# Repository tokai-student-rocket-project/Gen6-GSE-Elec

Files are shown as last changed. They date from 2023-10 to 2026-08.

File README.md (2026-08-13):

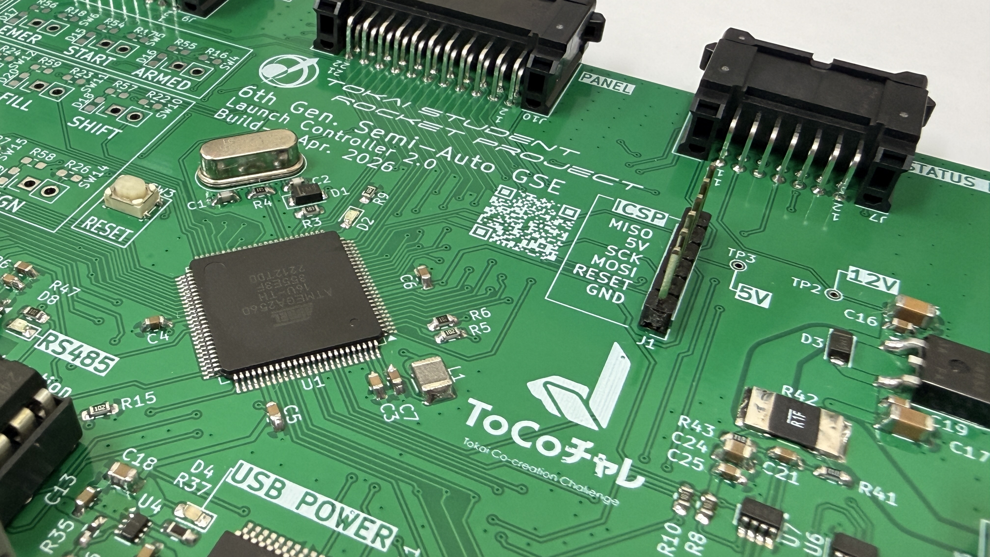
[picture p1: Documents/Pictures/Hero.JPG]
Hero


# 第6世代 Ground Support Equipment (GSE)

**2025年3月8日，H-60号機打上げ実験にて運用をし正常に動作したことを確認しました．**

## システムの特徴
- 🔋 **バッテリー給電 & 小型軽量化**: 従来の大型電源を撤廃し、フィールド運用が容易なバッテリー駆動に対応
- ⚡ **Arduino / PlatformIO 開発**: モジュール化された保守性の高いコード構造と自動ライブラリ管理
- 📊 **高精度 N2O 圧力リアルタイム計測**: VESIM10 圧力センサと ADS1115 ADC による遠隔圧力監視
- 🛡️ **フェールセーフ & 安全インターロック**: セミオートマチックシーケンスおよび緊急停止 (E-STOP) 機能

## 📌 バージョン履歴とシステム構成
本リポジトリでは、開発・運用の進展に合わせて以下のバージョンを管理しています。
| バージョン | 主な特徴・追加機能 | ソースファイル | PlatformIO 環境名 |
|---|---|---|---|
| **Gen6 1.0** | **初代実証版**<br>2025年3月8日 H-60号機打上げ実験にて運用成功。RS485有線通信、セミオートシーケンス | `src/LaunchController/`<br>`src/SatelliteController/` | `[env:Launch]`<br>`[env:Satellite]` |
| **Gen6 2.0** | **安全・安定性強化版**<br>電磁弁故障検出デバウンス、リミットスイッチ安全ゲート監視、ゼロ点校正の安全判定機能を追加、通信アルゴリズムを最適化 | `src/LaunchController2.0/`<br>`src/SatelliteController2.0/` | `[env:Launch2]`<br>`[env:Satellite2]` |

## ギャラリー
- [2025年3月8日 H-60号機打上げ実験](https://github.com/tokai-student-rocket-project/Gen6-GSE-Elec/blob/main/Documents/Pictures/Gallery/Gallery.md)

## ドキュメント
- [仕様](./Documents/Specification.md)
- [パーツリスト](./Documents/)
- [自動シークエンスタイミングの考え方](./Documents/AutoSequence.md)
- [通信・タスク管理ライブラリについて](./Documents/library_guide.md)
- [亜酸化窒素の圧力計測について](./Documents/VESIM10_Manual.md)
  - [校正シート](./Documents/VESIM10_Calibration.xlsx)
  - [試験成績表(TSRP Only)](https://u-tokai.box.com/s/f19nbcfg3vuwrdxsdca0jw9x3lm8z8kp)

## フォルダ構成

## .pio
: 基本的に自動生成されるため必要ないですが，ライブラリの関係で置いてあります．.pioフォルダの役割は外部ライブラリのインストール先とbuild時のファイル生成先です．（たぶん）

## [Document](./Documents/)
: 資料保管場所として使用しています．できる限りの情報を残せるように頑張ります．
## [include](./include/)
: 特に使用していません．(PlatformIO自動生成)
## [KiCad](./KiCad/)
: サテライトコントローラーランチコントローラーの基板が入っています．フォルダ名の通り，オープンソースのEDAである[KiCad](https://www.kicad.org/)を使用して作成しました．バージョンは 8.0 です．(2025年1月中に9.0へと上がるみたいでびっくりしています．)
## [lib](./lib/)
: ライブラリが入っています．新しくライブラリを作成する際はこちらに収納すると分かりやすいです．(PlatformIO自動生成)
## [src](./src/)
: ランチコントローラーとサテライトコントローラーのソースファイルが入っています．Arduinoで記述していますが，[PlatformIO](https://platformio.org/)の仕様上 .ino ファイルではなく，.cppファイルになっています．(PlatformIO自動生成)
## [test](./test/)
: test機能を使っていないので意味はありません．(PlatformIO自動生成)
## [LICENCE](./LICENSE)
: ライセンスを記載しています．
## [platformio.ini](./platformio.ini)
: PlatformIOを使用するための設定ファイルとなっています．参照：[platform.iniについて](#platforminiについて)

## platform.iniについて

platform.iniはPlatformIOを使用するための設定ファイルです．外部ライブラリがインストールされていなくてもこのplatform.iniファイルに記載があれば自動的にインストールしてくるため環境構築を行いやすくなり，とても便利です．参照：[公式](https://docs.platformio.org/en/latest/projectconf/index.html)

platform.iniファイルにはセクションがあり，それぞれに対してKeyとValueのペアがあります．

> [!NOTE]
> ここの説明を読むより，[公式](https://docs.platformio.org/en/latest/projectconf/index.html)の説明を読んだ方が正確で分かりやすいです！

### サテライトコントローラー
[env:Satellite]
> 環境を示しています．今回はサテライトコントローラーの環境になります．

platform = atmelavr
> 使用するマイコンに合わせています．参照：[公式](https://docs.platformio.org/en/latest/projectconf/sections/env/options/platform/platform.html)

board = ATmega2560
> 使用するマイコンが持つ固有の値を入れています．参照：[公式](https://docs.platformio.org/en/latest/projectconf/sections/env/options/platform/board.html)

framework = arduino
> 使用したいフレームワークを指定しています．参照：[公式](https://docs.platformio.org/en/latest/frameworks/index.html#frameworks)

monitor_speed = 115200
> シリアルモニターのボーレートを指定しています．なお，VScodeの拡張機能である Serial Monitor を使用する場合は拡張機能側で設定する必要があるため関係ありません．

upload_protocol = arduinoisp
> ArduinoISP を使用して書き込むため指定しています．（シリアル変換ICの影響か，USB経由で書き込みができなかったため．つけていて良かった．）

upload_speed = 19200
> ArduinoISP 周りの設定です．
upload_flags = ...
> ArduinoISP 周りの設定です．
upload_command = ...
> ArduinoISP 周りの設定です．

build_src_filter = +<SatelliteController/SatelliteController.cpp>
> env:Satellite の環境に書き込みたいソースファイルを指定できます．

lib_deps = ...
> 外部ライブラリを指定しています．

### ランチコントローラー
[env:Launch]
platform = atmelavr
> 環境を示しています．今回はランチコントローラーの環境になります．

board = ATmega2560
> [platform.ini > サテライトコントローラー参照](#サテライトコントローラー)

framework = arduino
> [platform.ini > サテライトコントローラー参照](#サテライトコントローラー)

monitor_speed = 115200
> [platform.ini > サテライトコントローラー参照](#サテライトコントローラー)

lib_deps = ...
> [platform.ini > サテライトコントローラー参照](#サテライトコントローラー)

build_src_filter = +<LaunchController/LaunchController.cpp>
> [platform.ini > サテライトコントローラー参照](#サテライトコントローラー)

### 手順書
- [せいさくちゅう](./)

### データフロー

- [ランチコントローラー](./Documents/Pictures/DataFlowDiagram/LaunchController_DataFlowDiagram.png)

- [サテライトコントローラー](./Documents/Pictures/DataFlowDiagram/SatelliteController_DataFlowDiagram.png)

## License

Copyright (c) 2025 Tokai Student Rocket Project

This project is licensed under the MIT License. See the [LICENSE](https://github.com/tokai-student-rocket-project/Gen6-GSE-Elec/blob/main/LICENSE) file for mare details.

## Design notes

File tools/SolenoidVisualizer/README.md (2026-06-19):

# Gen6-GSE Solenoid Visualizer

Gen6-GSEシステムの電磁弁（ソレノイド）の動作状態を可視化・シミュレーションするためのGUIツールです．

## 動作要件 (Requirements)

Python 3 環境が必要です．
実行前に以下の外部ライブラリを `pip` でインストールしてください．

```bash
pip install customtkinter pyserial
```

※ `tkinter` は通常Pythonに標準で同梱されていますが，Linux環境等では別途インストールが必要な場合があります（例: `sudo apt-get install python3-tk`）．

## 実行方法 (How to Run)

Pythonインタプリタを使用して `main.py` を実行します．
（注: `python tools/SolenoidVisualizer` のようにディレクトリを指定するだけではエラーになります．必ず `main.py` まで指定してください）

**方法1: プロジェクトのルートディレクトリから実行する場合**
```bash
python tools/SolenoidVisualizer/main.py
```

**方法2: ツールのディレクトリに移動して実行する場合**
```bash
cd tools/SolenoidVisualizer
python main.py
```

## 主な機能 (Features)

- **シリアル通信モニタ:** Launch Controllerとシリアル通信で接続し，リアルタイムのコマンド(CMD)とフィードバック(FB)の状態を可視化します．
- **デバッグモード (DEBUG MODE):** ハードウェアがなくても，チェックボックスから各電磁弁を強制的にON/OFFし，配管内の流体（GN2, LN2O, GO2）の動きをシミュレーションできます．
- **自動シーケンス (AUTO LAUNCH):** `LaunchController2.0.cpp` のタイミング（充填，酸素，点火，主弁開，パージなど）に合わせた自動打ち上げシーケンスをGUI上でテスト・可視化できます．

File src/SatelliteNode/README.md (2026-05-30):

# SatelliteNode

Seeed XIAO SAMD21 を用いたサテライトノードのファームウェアです。  
リミットスイッチの状態を RS485 通信で SatelliteController2.0 に送信します。

---

## ハードウェア構成

### マイコン

| 項目 | 内容 |
|---|---|
| ボード | Seeed XIAO SAMD21 |
| フレームワーク | Arduino (PlatformIO) |
| 環境名 | `SatelliteNode` |

### ピン配置

| 機能 | ハード記述 | Arduino ピン | 説明 |
|---|---|---|---|
| RS485 RE/DE 制御 | GPIO0 | D0 | HIGH=送信, LOW=受信 |
| 5V電源電圧計測 (ADC) | GPIO1 | A1 | 10kΩ×2 分圧入力 |
| RS485 DI (TX) | GPIO16 | D6 | `Serial1` TX |
| RS485 RO (RX) | GPIO17 | D7 | `Serial1` RX |
| I2C SDA | GPIO22 | D4 | `Wire` SDA |
| I2C SCL | GPIO23 | D5 | `Wire` SCL |

### RS485 トランシーバ (ADM2582E)

| ADM2582E ピン | 接続先 |
|---|---|
| RE (Low=受信有効) | D0 (GPIO0) |
| DE (High=送信有効) | D0 (GPIO0) |
| DI | D6 / TX (GPIO16) |
| RO | D7 / RX (GPIO17) |

RE と DE は同一ピンに接続されており，HIGH で送信モード，LOW で受信モードとなります。

### IOエキスパンダー (MCP23017)

I2C アドレス: `0x20` (A0〜A2 = GND)

| MCP23017 ピン | 論理チャンネル | 方向 | 説明 |
|---|---|---|---|
| GPA0 | チャンネル2 | 入力 | リミットスイッチ入力2 (74HC14経由) |
| GPA1 | チャンネル1 | 入力 | リミットスイッチ入力1 (74HC14経由) |
| GPA2 | チャンネル0 | 入力 | リミットスイッチ入力0 (74HC14経由) |
| GPA3 | チャンネル5 | 入力 | リミットスイッチ入力5 (74HC14経由) |
| GPA4 | チャンネル4 | 入力 | リミットスイッチ入力4 (74HC14経由) |
| GPA5 | チャンネル3 | 入力 | リミットスイッチ入力3 (74HC14経由) |
| GPB0 | — | 出力 | LED制御0 (チャンネル0対応) |
| GPB1 | — | 出力 | LED制御1 (チャンネル1対応) |
| GPB2 | — | 出力 | LED制御2 (チャンネル2対応) |
| GPB3 | — | 出力 | LED制御3 (チャンネル3対応) |
| GPB4 | — | 出力 | LED制御4 (チャンネル4対応) |
| GPB5 | — | 出力 | LED制御5 (チャンネル5対応) |

> **注意**: 74HC14 はシュミットトリガインバータです。  
> リミットスイッチが押される（導通する）と 74HC14 の入力が LOW となり，出力が HIGH になります。  
> そのため，`MCP23017 GPA ピン = HIGH` のとき，対応するリミットスイッチが押されていることを意味します。

### A/D 変換（5V電源電圧計測）

```
5V 電源
  │
  ├─ 10kΩ (R1, 1%)
  │
  ├─── A1 (ADC 入力)
  │
  ├─ 10kΩ (R2, 1%)
  │
GND
```

分圧比 = R2 / (R1 + R2) = 10k / 20k = **0.5**

ADC 基準電圧は 3.3V，分解能は 10bit です。

計算式:
```
V_adc = (analogRead(A1) / 1023.0) × 3.3
V_supply = V_adc / 0.5 = V_adc × 2.0
```

---

## ソフトウェア仕様

### 送信パケット

| パケット種別 | 値 | 内容 |
|---|---|---|
| `LIMIT_SWITCH_SYNC` | 10 | リミットスイッチ状態 (uint8_t) |
| `COM_CHECK_S_TO_L` | 4 | 生存確認 |

#### LIMIT_SWITCH_SYNC ビット定義

| ビット | チャンネル | 押されているとき |
|---|---|---|
| Bit0 | チャンネル0 (GPA2) | `1` |
| Bit1 | チャンネル1 (GPA1) | `1` |
| Bit2 | チャンネル2 (GPA0) | `1` |
| Bit3 | チャンネル3 (GPA5) | `1` |
| Bit4 | チャンネル4 (GPA4) | `1` |
| Bit5 | チャンネル5 (GPA3) | `1` |

### 受信パケット

| パケット種別 | 値 | 内容 |
|---|---|---|
| `COM_CHECK_L_TO_S` | 3 | 生存確認 (受信時刻を更新) |

### タスク周期

| タスク | 周期 |
|---|---|
| リミットスイッチ状態送信 | 10 Hz |
| 5V電源電圧計測 | 5 Hz |
| 生存確認送信 | 2 Hz |

---

## ビルド方法

```bash
# PlatformIO CLI の場合
pio run -e SatelliteNode

# 書き込み
pio run -e SatelliteNode -t upload
```

> `platformio.ini` の `[env:SatelliteNode]` に以下を追加する必要があります（詳細は `SatelliteNode_bugs.md` を参照）。

---

## 依存ライブラリ

| ライブラリ | 用途 |
|---|---|
| `Lib_MCP23017` (本プロジェクト内) | MCP23017 IOエキスパンダー制御 |
| `hideakitai/MsgPacketizer` | RS485 パケット通信 |
| `hideakitai/TaskManager` | 定周期タスク管理 |

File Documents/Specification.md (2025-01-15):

# 第6世代 Ground Support Equipment (GSE) 仕様

## ランチコントローラー
<div align = "center">
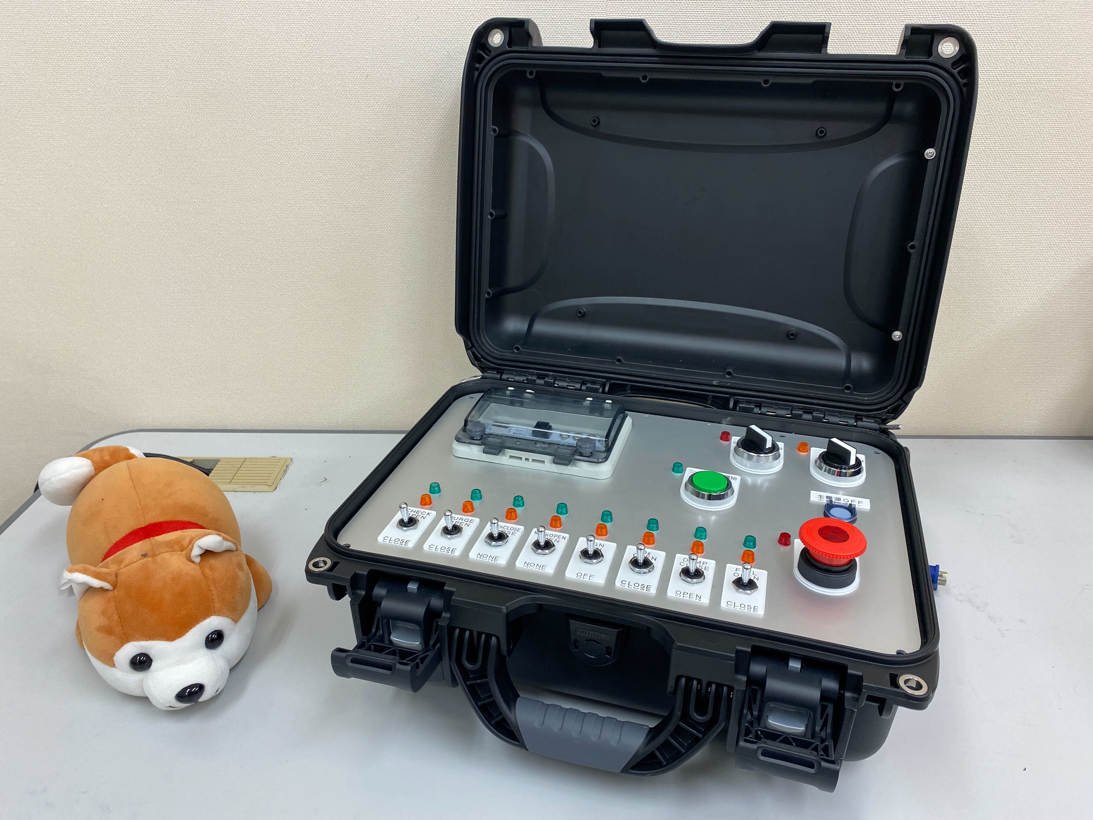
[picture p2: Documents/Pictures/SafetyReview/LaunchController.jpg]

</div>

ロケットから離れた点火所から酸化剤充填を行うコントローラーです．
セミオートマチックシークエンスに対応しています．

### 電源

電源はポータブルバッテリーから得る想定で設計されていますが，12 V（DC）の AC アダプターを使用できればどのような電源でも構いません．
DCジャックは**センタープラス**なので，センタープラスのACアダプターを使用してください．

### 通信

サテライトコントローラーとRS485を用いて有線通信しています．

|通信仕様||
|-|-|
|想定通信距離|100 m 以上|
|ケーブル|LANケーブル（ツイストペア・シールド無し）|
|コネクタ|RJ45モジュラージャック|

### インターフェース

ランチコントローラーには各種装置と接続するためのインターフェースがついています．

#### 左側面

|名称|個数|説明|
|-|-|-|
|2.1 mm DCジャック|3|充填確認スイッチが接続できます．|
|3.5 mm ステレオミニジャック|1|外部音声出力ポートです．AUXケーブルを使用できます．|

#### 右側面
|名称|個数|説明|
|-|-|-|
|2.1 mm DCジャック|1|電源入力に使います．参照：[電源](#電源)|

#### 背面
|名称|個数|説明|
|-|-|-|
|RJ45モジュラージャック|1|通信ケーブルを接続し，サテライトコントローラーと有線通信を行います．|

## パネル
<div align = "center">
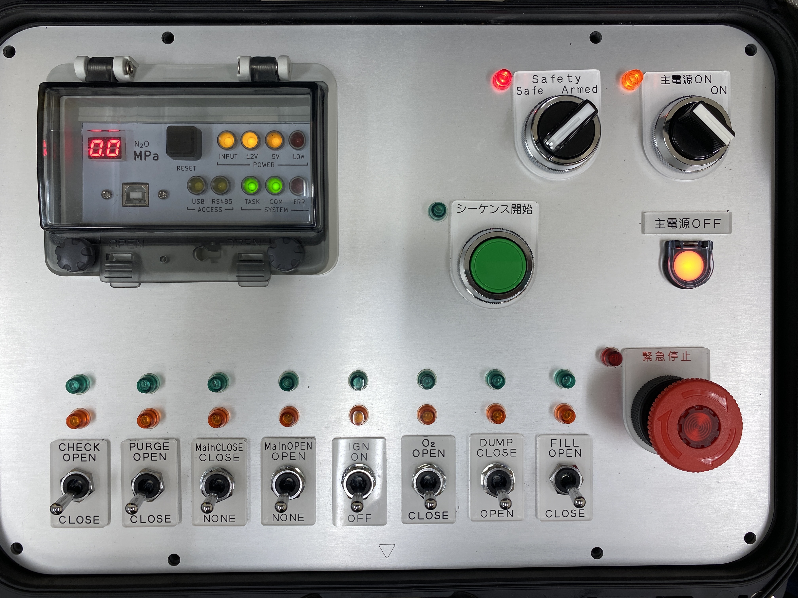
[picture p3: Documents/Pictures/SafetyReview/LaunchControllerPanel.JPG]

</div>

ロケットを打上げる操作パネルとなっています．

画像左上はステータスパネルとなっており，GSEの状態確認ができるようになっています．プログラムを書き込み時やデバッグ時にハッチを開けて USB Type-B を介してマイコンにアクセスできるようになっている．

> [!NOTE]
> シリアルポートはSerialを使用できます．
> 
> Serial.begin(115200)で初期化．
> Serial.println()で任意の値を取得することができます．

## サテライトコントローラー
<div align = "center">
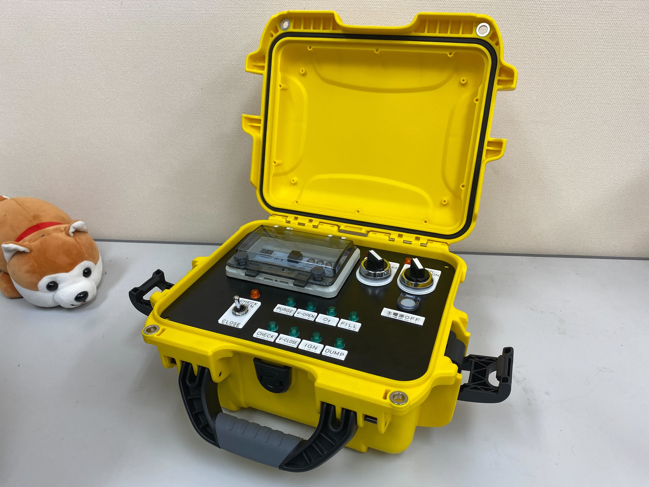
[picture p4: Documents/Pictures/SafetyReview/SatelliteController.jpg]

</div>

ロケットの近くに設置され，ランチコントローラーからの指令を受けて，各種装置へ出力を行う中継装置です．

最大6個の電磁弁に対応しています．

#### 電源
ランチコントローラーと同様に電源はポータブルバッテリーから得る想定で設計していますが，12 V(AC)アダプターを使用できればどのような電源でも構いません．
DCジャックは**センタープラス**なので，センタープラスのACアダプターを使用してください．

#### 通信
ランチコントローラーとRS485を用いて通信しています．

|通信仕様||
|-|-|
|想定通信距離|100 m 以上|
|ケーブル|LANケーブル（ツイストペア・シールド無し）|
|コネクタ|RJ45モジュラージャック|

#### インターフェース

サテライトコントローラーは中継装置の役割をしているため各種装置へつながる便利なインターフェースがついています．

#### 左側面

|名称|個数|説明|
|-|-|-|
|コネクタ（4ピン・大）|1|アンビリカルケーブルを接続します．IGN，バルブOPENの信号を出力します．|

#### 右側面
|名称|個数|説明|
|-|-|-|
|2.1 mm DCジャック|1|電源入力に使います．参照：[電源](#電源)|

#### 背面
|名称|個数|説明|
|-|-|-|
|RJ45モジュラージャック|1|通信ケーブルを接続し，サテライトコントローラーと有線通信を行います．|
|コネクタ（2ピン）|1|こもあユニットへ接続します．12 Vを出力します．|
|コネクタ（4ピン・小）|1|将来的に亜酸化窒素の圧力を読み取る圧力センサが取り付けられます．|
|コネクタ（11ピン）|1|電磁弁ユニットへ接続します．|

## こもあユニット
<div align = "center">
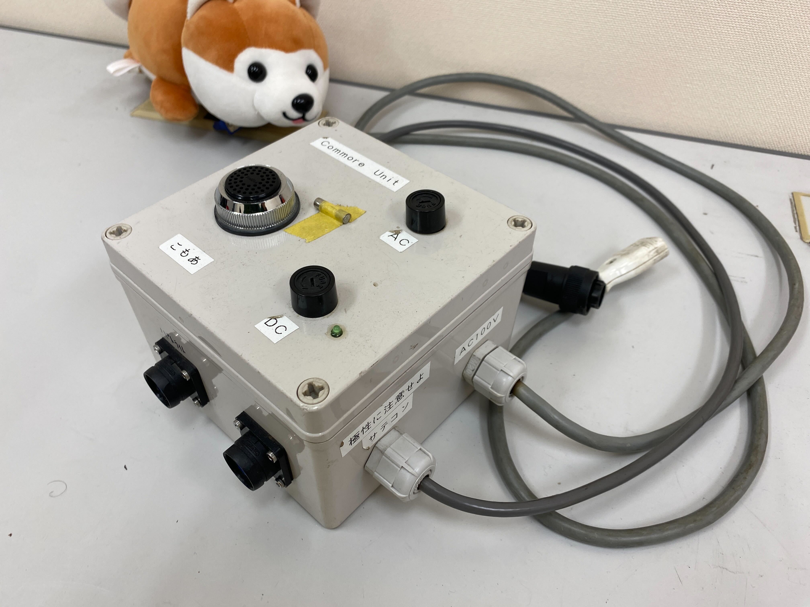
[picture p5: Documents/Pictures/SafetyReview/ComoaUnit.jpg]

</div>

1次側に信号が入力されると2次側にAC100V出力します．リレーと同じ役割をしています．

## アンビリカルケーブル
<div align = "center">
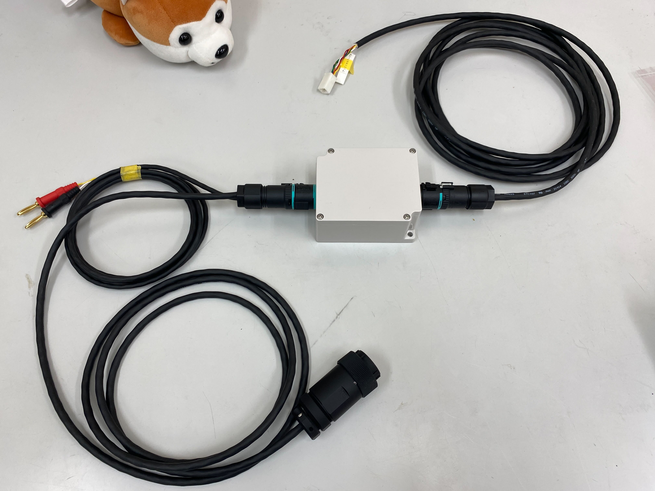
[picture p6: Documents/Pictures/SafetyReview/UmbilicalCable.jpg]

</div>

ロケットに電力と信号を供給するためのケーブルです．画像中央のBOXを基準とし，右側がロケットに接続（搭載計器）され，左側が電源とサテライトコントローラーに接続されます．左側にある黒色のコネクタが4ピンコネクタ・大です．

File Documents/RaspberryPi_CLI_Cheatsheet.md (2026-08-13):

# Raspberry Pi 4 CLI 活用・運用チートシート (Gen6 GSE System)

本ドキュメントは，Gen6 GSE システム（Launch3.0 / Satellite3.0）の無線遠隔制御ノードとして使用する **Raspberry Pi 4 の環境構築，ネットワーク設定，遠隔制御プログラムの起動・デバッグ，systemd サービス管理，電源操作** において頻繁に使用する CLI コマンドをまとめた活用ガイドです．

---

## 1. 接続・ネットワーク疎通確認 (SSH & IP)

| コマンド | 説明 |
|---|---|
| `ssh pi@raspi-gse.local` | mDNS ホスト名指定で SSH ログイン |
| `ssh pi@192.158.x.x` | IP アドレス直接指定で SSH ログイン |
| `hostname -I` *(または `ip a`)* | Raspberry Pi に割り当てられている IP アドレスを確認 |
| `ping 192.158.x.x` | PC から Raspberry Pi へのネットワーク疎通確認 |

---

## 2. 固定 IP アドレス設定 (NetworkManager)

Raspberry Pi OS (Debian Bookworm) では NetworkManager を使用して固定 IP（`192.158.x.x` 等）を設定します．

| コマンド | 説明 |
|---|---|
| `sudo nmtui` | GUI 風の対話画面で Wi-Fi および固定 IP アドレスを設定（推奨） |
| `nmcli connection show` | 現在認識されているネットワーク接続名の一覧を表示 |
| `sudo nmcli connection modify "<接続名>" ipv4.method manual ipv4.addresses 192.158.x.x/24 ipv4.gateway 192.158.x.1` | コマンドラインで指定の IP アドレスを固定化 |
| `sudo nmcli connection up "<接続名>"` | 変更したネットワーク設定を即時適用 |

---

## 3. OS 更新・パッケージ管理 (Apt & Pip)

| コマンド | 説明 |
|---|---|
| `sudo apt update && sudo apt upgrade -y` | OS パッケージリスト更新と全パッケージの最新化 |
| `sudo apt install -y python3-pip python3-serial python3-msgpack python3-flask git` | 遠隔制御システムに必要な依存パッケージを一括インストール |
| `pip3 install -r requirements.txt --break-system-packages` | `raspi_gse_control` の Python パッケージ依存関係を適用 |

---

## 4. 制御プログラムの配置と実行 (GSE Control Server)

| コマンド | 説明 |
|---|---|
| `scp -r d:\Projects\TSRP\Gen6-GSE-Elec\tools\raspi_gse_control pi@192.158.x.x:~/` | Windows PC から Raspberry Pi へ制御プログラム一式を SCP 転送 |
| `python3 raspi_gse_control.py --demo` | **デモ / シミュレータモード** 起動（マイコン実機なしで通信・Web UI テスト可能） |
| `python3 raspi_gse_control.py --port /dev/ttyUSB0` | **実機接続モード** 起動（ATmega2560 マイコンと USB シリアル接続） |

---

## 5. ターミナル CLI デバッグコマンド (`GSE-Debug>` プロンプト内)

`raspi_gse_control.py` 起動後に画面に表示される `GSE-Debug>` 画面での直感操作コマンドです．

| コマンド | 引数例 | 説明 |
|---|---|---|
| `status` | - | 現在の圧力（MPa），セーフティ，リミットスイッチ，各弁状態（CMD/FB）一覧表示 |
| `arm` | `on` / `off` | 遠隔セーフティ装置の解除 (ARM) / 施錠 (DISARM) |
| `fill` | - | 遠隔充填シーケンス開始 |
| `ignite` | - | 遠隔点火シーケンス開始 |
| `estop` | - | 🚨 **緊急停止 (EMERGENCY STOP)**（DUMP, PURGE 開，全安全退避） |
| `peace` | - | 通常停止 (PEACEFUL STOP) |
| `valve` | `FILL 1` | 指定電磁弁の手動トグル (`SHIFT`, `FILL`, `DUMP`, `OXYGEN`, `IGNITER`, `OPEN`, `CLOSE`, `PURGE`) |
| `limit` | `1` / `0` | リミットスイッチ (ch5) の模擬押下 / 解放 |
| `zero` | - | 圧力センサーの遠隔ゼロ点校正要求 |
| `quit` | - | GSE デバッグターミナルおよびサーバーの終了 |

---

## 6. 自動起動サービス管理 (systemd)

実験場等で電源投入時にバックグラウンドで自動起動・継続稼働させるための管理コマンドです．

| コマンド | 説明 |
|---|---|
| `sudo cp raspi-gse.service /etc/systemd/system/` | サービス設定ファイルを配置 |
| `sudo systemctl daemon-reload` | systemd にサービス定義を再読み込み |
| `sudo systemctl enable raspi-gse.service` | OS 起動時の自動スタートを有効化 |
| `sudo systemctl start raspi-gse.service` | 今すぐバックグラウンドサービスを起動 |
| `sudo systemctl stop raspi-gse.service` | バックグラウンドサービスを一時停止 |
| `sudo systemctl status raspi-gse.service` | サービスの現在状態（稼働中/停止中）を表示 |
| `journalctl -u raspi-gse.service -f` | 自動起動プログラムのリアルタイム標準出力ログを監視 |

---

## 7. 電源操作 (Shutdown & Reboot)

> [!CAUTION]
> SD カードのデータ破損を防ぐため，電源プラグを抜く前に必ず安全なシャットダウンコマンドを実行してください．

| コマンド | 説明 |
|---|---|
| `sudo shutdown -h now` *(または `sudo poweroff`)* | **安全なシャットダウン**（緑色のアクセス LED 消灯を確認後に電源抜去） |
| `sudo reboot` | システムの即時再起動 |

---

## 8. 関連ドキュメントリンク

* [RaspberryPi_OS_Comparison_and_Setup.md](file:///d:/Projects/TSRP/Gen6-GSE-Elec/Documents/RaspberryPi_OS_Comparison_and_Setup.md)
* [RaspberryPi_Debug_and_Demo_Guide.md](file:///d:/Projects/TSRP/Gen6-GSE-Elec/Documents/RaspberryPi_Debug_and_Demo_Guide.md)
* [Launch3_Satellite3_Wireless_Guide.md](file:///d:/Projects/TSRP/Gen6-GSE-Elec/Documents/Launch3_Satellite3_Wireless_Guide.md)
* [raspi-gse.service](file:///d:/Projects/TSRP/Gen6-GSE-Elec/tools/raspi_gse_control/raspi-gse.service)

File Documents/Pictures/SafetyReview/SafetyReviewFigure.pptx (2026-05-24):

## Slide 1

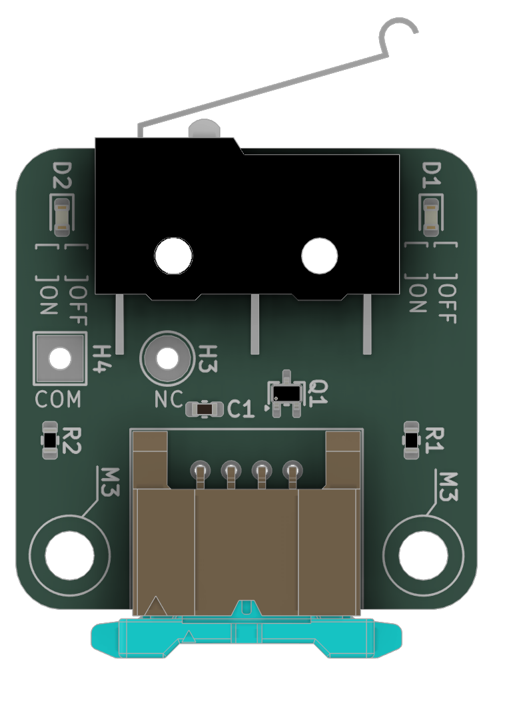
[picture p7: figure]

検知

スイッチ

※配線し
はんだ付け

信号出力

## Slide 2

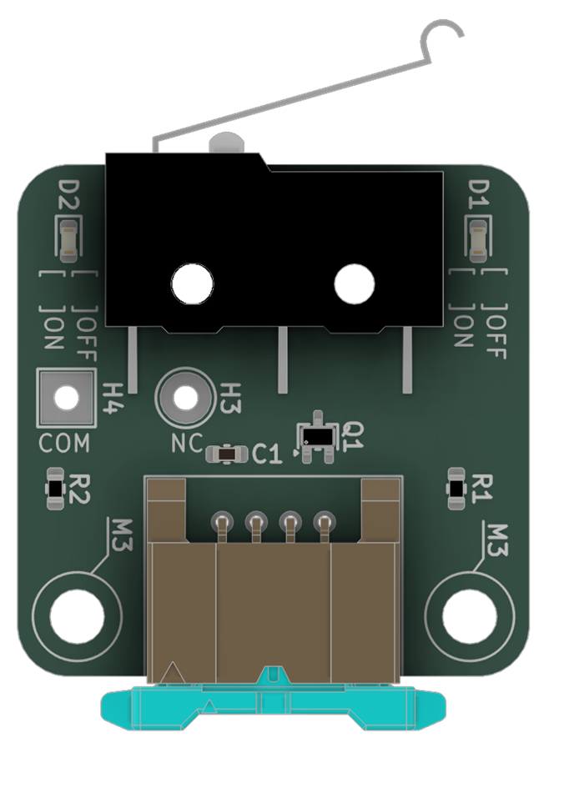
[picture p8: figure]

検知

1 2 3 4

| 1 | 2 | 3 | 4
ピン名 | GND | 3.3V IN | SW OUT | LED CTRL
機能 | 基準電位 | 電源入力 | 出力 | LED制御

信号出力

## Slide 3

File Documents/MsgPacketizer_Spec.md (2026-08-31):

# MsgPacketizer システム仕様とトラブルシューティング記録

## 概要
Arduino/MCU 側で `MsgPacketizer` ライブラリを使用してシリアル通信を行う際、C++（PlatformIO）側の必須ビルドオプションと、Raspberry Pi（Python）側で正しくデータを受信・送信するための仕様、およびデバッグで判明したトラブルの根本原因を記録する。

## C++ (PlatformIO) 側の必須ビルドオプション (`platformio.ini`)

MsgPacketizer および内部で使用される MsgPack は、マイコンの貴重なメモリ（RAM）を節約するため、静的なメモリ確保を行っています。そのため、デフォルトではかなり厳しい要素数・登録数の上限が設定されています。
今回の GSE/サテライトシステムでは扱うデータ量や通信ポートが多いため、`platformio.ini` の `build_flags` にて以下のマクロを定義して上限を拡張しています。

### 1. `-D PACKETIZER_MAX_STREAM_MAP_SIZE=4`
- **概要:** MsgPacketizer が同時に処理（監視）できる通信ストリーム（`Serial` や `Serial1`、`Wire` など）の最大登録数を指定する設定。
- **解説:** 今回のシステムでは、LaunchController が「デバッグ・RasPi通信用のUSB (`Serial`)」と「サテライト通信用のRS485 (`Serial1`)」の **2つのシリアルストリーム** を同時に監視・パースする必要があります。デフォルトの上限設定（通常は1か2）では複数ポートの同時登録が弾かれてしまうリスクがあるため、安全率を見込んで最大 `4` ストリームまで処理できるように拡張しています。
- **影響:** この設定が不足していると、後から登録したシリアルポートからのパケットが無視され、`MsgPacketizer::update()` を呼んでもコールバックが一切呼ばれなくなるという原因不明の通信不良に陥ります。

### 2. `-D PACKETIZER_MAX_CALLBACK_QUEUE_SIZE=12`
- **概要:** 登録できるコールバック関数（`subscribe`）の最大数を指定する設定。
- **解説:** コマンドの種類（バルブ制御、テレメトリ、Ping等）が増えて `subscribe` を多数登録しようとした際、デフォルト上限を超えると後から登録したコマンドが反応しなくなります。これを 12 に増やすことで、多数のコマンドを漏れなく受け付けられるようにしています。

### 3. `-D MSGPACK_MAX_ARRAY_SIZE=12`
- **概要:** MsgPack の1つの配列（リスト）に格納できる要素数の上限設定。
- **解説:** デフォルト上限は 8個です。テレメトリデータ（圧力、電圧、各バルブ状態など）の変数が 9個以上に増えた際、デフォルトのままでは送信時のエンコード処理が失敗してデータが一切送られなくなります。これを回避するために 12 に拡張しています。

---

## MsgPacketizer のプロトコル仕様 (C++ -> Python)
MsgPacketizer が生成するシリアル通信の1フレームは以下の構造になっている。

```text
[COBS Overhead/Lengths] [Packet ID (Index)] [MsgPack Data Payload] [CRC8] [0x00 (Delimiter)]
```

### 1. COBS (Consistent Overhead Byte Stuffing)
- **仕様:** 
  - フレームの区切り文字として `0x00` を使用する。
  - データペイロード内に `0x00` が含まれる場合、そのまま送信するとフレームの区切りと誤認されるため、COBSエンコードによって `0x00` が排除され、次の `0x00` までの長さを示すバイトに置き換えられる。
- **注意点:** 
  - 受信側（Python）は、MsgPackのデコードを行う**前**に、必ずCOBSデコードを行い、元のペイロードを復元しなければならない。これを怠ると、データ中に `0x00`（例：値が `0` の整数など）が含まれた瞬間にパケットが破損したように見え、以降のデコードが失敗する。

### 2. CRC8 チェックサムの計算範囲
- **仕様:**
  - 多項式: `0x07` (SMBus / FastCRC8::smbus と同等)
  - 計算範囲: **MsgPack データペイロード本体のみ（`packet_id` を除く）**
- **注意点:**
  - Python 側で CRC を計算・検証する際、`[packet_id] + [msgpack data]` の全体に対して CRC を計算すると不一致となる。必ず `packet_id` を除外した `[msgpack data]` 部分に対して CRC8 を計算すること。

### 3. `send()` と `send_arr()` の違いと Python 側の受け皿
- **仕様:**
  - `MsgPacketizer::send()`: 引数を MsgPack の「独立した複数の要素」として直列にエンコードする。
  - `MsgPacketizer::send_arr()`: 引数を MsgPack の「1つの配列（Array）」としてエンコードする。
- **注意点:**
  - 今回実装した Python のシリアルワーカーでは、どちらの関数で送信されても問題なく処理できるように、受信した全要素を Python 側で強制的に1つのリスト `[packet_id, arg1, arg2...]` にパッキング（またはアンラップ）して後続の処理に渡すラッパー機構を実装した。

---

## 今回発生したトラブルと原因リスト

1. **配列の要素数制限による送信失敗**
   - **症状:** 新たに入力電圧と12Vバス電圧の2つの要素を追加したところ、データが全く送信されなくなった。
   - **原因:** 追加により引数が 9 個となり、デフォルトの `MSGPACK_MAX_ARRAY_SIZE` (8) を超過してエンコードが失敗していた。
   - **解決策:** `platformio.ini` に `-D MSGPACK_MAX_ARRAY_SIZE=12` を追記。

2. **COBS エンコード未対応によるパケット崩壊**
   - **症状:** Python スクリプトでは全くデータを受信できなかった。
   - **原因:** 元の Python スクリプトに COBS デコードが実装されておらず、シリアルの生データを直接 MsgPack デコーダに流し込んでいた。リミットスイッチのダミー値として `0`（`0x00`）を入れた瞬間に COBS によるバイト置換が発動し、MsgPack としての構造が崩壊した。
   - **解決策:** Python スクリプト内に `cobs_decode` および `cobs_encode` を自前で実装し、パケットを抽出してから MsgPack デコーダに渡すように修正。

3. **CRC8 計算範囲の仕様不一致による全破棄**
   - **症状:** COBS デコードを実装しても、依然としてデータが更新されず、Python からの送信コマンドも MCU に無視された。
   - **原因:** Python 側で「パケットID」を含めて CRC8 を計算していたが、C++ 側の Packetizer は「パケットIDを含めず、データ本体のみ」で CRC を計算・照合する仕様だったため。
   - **解決策:** Python の CRC8 計算処理を修正し、`packet_id` を除外した `msgpack` バイト列のみを対象にチェックするように変更した。

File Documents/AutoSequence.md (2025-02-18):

# 自動シークエンスタイミングの考え方

## 基本的な考え方
酸化剤充填が完了した時，つまり充填確認スイッチが押された時を基準としてシークエンスが進む．
シークエンスが進む順番は以下の通り．
> FILL: 酸化剤充填 / パージ: 窒素放出による消火

1. FILL 開始
2. 酸素充填開始
3. イグナイター点火開始
4. バルブ開
5. FILL 停止
6. 酸素充填停止
7. イグナイター点火停止
8. パージ開始
9. パージ停止

## ignition関数

基本的なシークエンスをプログラムでは void sequence::ignition() が担っている．戻り値なし，引数なしの sequence 名前空間，ignition関数である．

ignition関数を下記に示す．

```
void sequence::ignition()
{
    // 重複実行防止
    if (sequence::ignitionSequenceIsActive)
        return;
    
    // 通信失敗したら点火シーケンスに進めない
    if (!communication::statusLamp.isHigh())
    {
        sequence::peacefulStop();
        return;
    }

    // エマスト中は点火シーケンスを始めない
    if (sequence::emergencyStopSequenceIsActive)
        return;

    // 充填開始前は点火シーケンスを始めない
    if (!control::fill.isAutomaticRaised())
        return;

    // 手動のFILLがONの間は点火シーケンスを始めない
    if (control::fill.isManualRaised())
        return;

    sequence::ignitionSequenceIsActive = true;
    sequence::canConfirm = false;

    control::sequenceStart.setAutomaticOn();
    mp3_play(4); // 0104_ignitionSequenceStart

    Tasks[control::OXYGEN_START]->startOnceAfterSec(4.5);

    Tasks[control::IGNITER_START]->startOnceAfterSec(6.0);

    Tasks[control::FILL_STOP]->startOnceAfterSec(10.0);
    Tasks[control::OPEN_START]->startOnceAfterSec(10.0);

    Tasks[control::OXYGEN_STOP]->startOnceAfterSec(10.5);
    Tasks[control::IGNITER_STOP]->startOnceAfterSec(10.5);
    Tasks[control::PURGE_START]->startOnceAfterSec(20.5);
    Tasks[control::PURGE_STOP]->startOnceAfterSec(25.5);
}
```
ここから特に必要な箇所を下記に示す．

```
    mp3_play(4); // 0104_ignitionSequenceStart

    Tasks[control::OXYGEN_START]->startOnceAfterSec(4.5);

    Tasks[control::IGNITER_START]->startOnceAfterSec(6.0);

    Tasks[control::FILL_STOP]->startOnceAfterSec(10.0);
    Tasks[control::OPEN_START]->startOnceAfterSec(10.0);

    Tasks[control::OXYGEN_STOP]->startOnceAfterSec(10.5);
    Tasks[control::IGNITER_STOP]->startOnceAfterSec(10.5);
    Tasks[control::PURGE_START]->startOnceAfterSec(20.5);
    Tasks[control::PURGE_STOP]->startOnceAfterSec(25.5);
```
上の行から順番に見ていく．
```
    mp3_play(4); // 0104_ignitionSequenceStart
```
この行はマイクロSDカードに保存された4番目のファイルを指定し音声出力している．つまり，「充填が確認されました．点火します．5秒前 4, 3, 2, 1」である．
```
    Tasks[control::OXYGEN_START]->startOnceAfterSec(4.5);
```
この行からシークエンスの動作を実行している．イメージは「Tasks」というやることリストに「control::OXYGEN_START」を追加し，startOnceAfterSec(4.5)にあるように，4.5秒後に1度だけ実行するといった感じ．
「control::OXYGEN_START」は酸素の流路につながっている電磁弁をONにするという動作．

ここで，Tasks[control::OXYGEN_START]->startOnceAfterSec(4.5); をよく観察してみると主に2つの要素で出来上がっていることが分かる．
1つ目は control::OXYGEN_START，2つ目は startOnceAfterSec(4.5) である．
1つ目の control::OXYGEN_START は電磁弁の動作に置き換えると分かりやすいと思う．さらに，startOnceAfterSec(4.5) も（）の中の数字を n とおけば，n 秒後に動作する指示であることがなんとなく分かると思う．

続いて，この行を見ていく．
```
    Tasks[control::IGNITER_START]->startOnceAfterSec(6.0);
```
こちらも，やることリストに追加していくイメージは変わらない．
「Tasks」というやることリストに「control::IGNITER_START」を追加し，startOnceAfterSec(6.0) のとおり，6.0秒後に1度だけ実行する．

ここで，[基本的な考え方](#基本的な考え方)に戻ってみると，今まで見てきたことは2. 3. の項目に書かれていた動作と一致すると思う．これは，プログラムのルールとして，上から下に実行されるためである．そのため，これ以降の動作も[基本的な考え方](#基本的な考え方)に書かれている通りの順番で実行されていく．

## 実行タイミングの考え方
ここまで，シークエンスとプログラムの対応関係について見てきたがここからはその動作がどのタイミングで実行されるのかを見ていく．

基本的には，startOnceAfterSec()の引数を見ていけば良い．（）の中に書いてある有効数字2桁の数が引数である．

下記の行から見ていく．
```
    Tasks[control::OXYGEN_START]->startOnceAfterSec(4.5);
```
この行では startOnceAfterSec()の引数が4.5である．この理由は，この以前の動作
```
    mp3_play(4); // 0104_ignitionSequenceStart
```
にて「充填が確認されました．点火します．5秒前」を言い終わるまでに4.5秒必要なためである．
これは，ignition関数が呼ばれた直後から4.5秒後に実行されると考えるとさらに分かりやすいと思う．

では，エンジンに点火するタイミングつまり，主流路弁が開するタイミングは
```
    Tasks[control::OPEN_START]->startOnceAfterSec(10.0);
```
となっており，ignition関数が呼ばれた直後から10.0秒後である．この時間を基準として点火操作を時系列順にまとめればどの動作がどのタイミングで実行されるか理解しやすいと思う．

時系列順に整理した点火シークエンスを下記に示す．

|T|実行時間|動作|引数の値|
|-|-|-|-|
|T+|15|パージ 停止|25.5|
|T+|10|パージ 開始|20.5|
|T+|0.5|酸素充填 停止|10.5|
|T+|0.5|イグニッション 停止|10.5|
|T-|0|FILL 停止|10.0|
|T-|0|主流路弁 開|10.0|
|T-|4|イグニッション 開始|6.0|
|T-|5|酸素充填 開始|4.5|

音声と合うように0.1秒単位でそろえるのは難しい．ちょっとずれる．

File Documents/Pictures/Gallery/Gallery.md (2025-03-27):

# 第6世代GSE

## H60 大樹町 2025/03/08

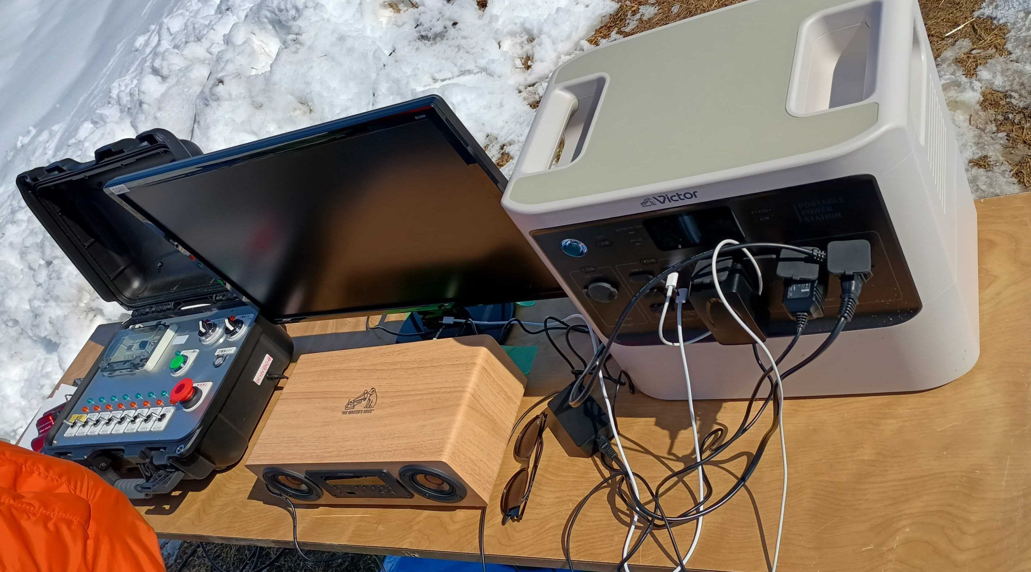
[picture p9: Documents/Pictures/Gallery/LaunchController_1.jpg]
LaunchController_Taiki


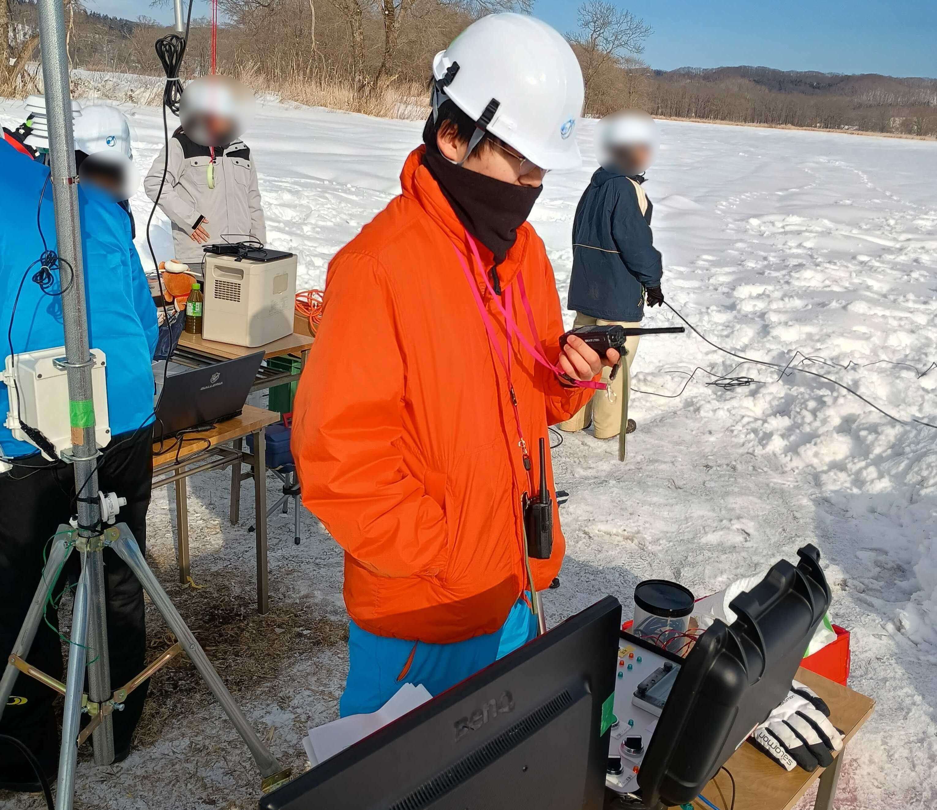
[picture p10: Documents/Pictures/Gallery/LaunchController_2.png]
LaunchController_Taiki


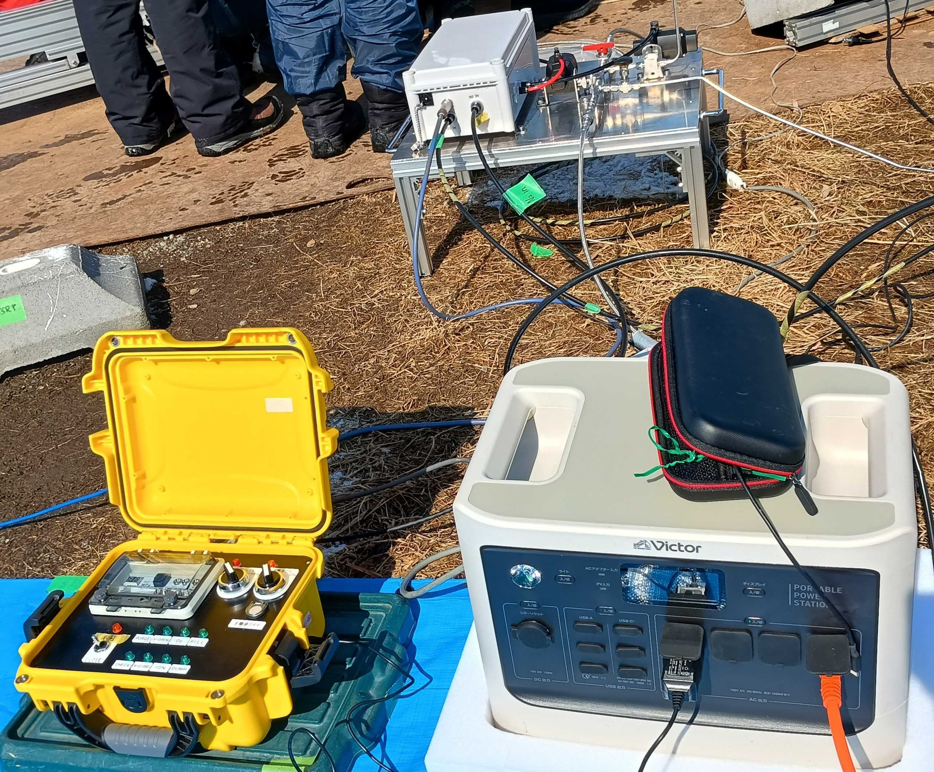
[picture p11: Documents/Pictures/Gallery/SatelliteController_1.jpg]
SatelliteController_Taiki


SatelliteController_Taiki

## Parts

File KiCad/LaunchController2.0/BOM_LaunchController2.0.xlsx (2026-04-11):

Reference | Qty | Value | Footprint | Datasheet | 価格 | (目安)部品の合計金額 | 在庫 | 必要な金額 | 合計金額 | TRUE
R38,R40,R41,R43 | 4 | 0R | Resistor_SMD:R_0603_1608Metric_Pad0.98x0.95mm_HandSolder | https://www.chip1stop.com/view/dispDetail/DispDetail?partId=ROHM-0021098 | ¥100 | ¥100 | TRUE | ¥0 | ¥15049 | FALSE
C1,C2 | 2 | 15pF | Capacitor_SMD:C_0603_1608Metric_Pad1.08x0.95mm_HandSolder | https://akizukidenshi.com/catalog/g/gP-13312/ | ¥100 | ¥100 | FALSE | ¥100
C29,C30,C32,C33,C34 | 5 | 0.01uF | Capacitor_SMD:C_0603_1608Metric_Pad1.08x0.95mm_HandSolder | https://akizukidenshi.com/catalog/g/gP-16143/ | ¥100 | ¥100 | FALSE | ¥100
C3,C4,C5,C6,C7,C8,C10,C11,C12,C16,C19,C23,C25,C26,C27,C31 | 16 | 0.1uF | Capacitor_SMD:C_0603_1608Metric_Pad1.08x0.95mm_HandSolder | https://akizukidenshi.com/catalog/g/gP-16143/ | ¥100 | ¥100 | TRUE | ¥0
C13,C14 | 2 | 1uF | Capacitor_SMD:C_0603_1608Metric_Pad1.08x0.95mm_HandSolder | https://akizukidenshi.com/catalog/g/gP-16143/ | ¥100 | ¥100 | FALSE | ¥100
C9 | 1 | 4.7uF | Capacitor_SMD:C_0603_1608Metric_Pad1.08x0.95mm_HandSolder | https://akizukidenshi.com/catalog/g/gP-16143/ | ¥100 | ¥100 | FALSE | ¥100
C18,C22,C24 | 3 | 10uF | Capacitor_SMD:C_0805_2012Metric_Pad1.18x1.45mm_HandSolder | https://akizukidenshi.com/catalog/g/g113388/,https://akizukidenshi.com/catalog/g/gP-16143/ | ¥100 | ¥100 | FALSE | ¥100
L1 | 1 | 10uH | Inductor_SMD:L_1210_3225Metric_Pad1.42x2.65mm_HandSolder | https://akizukidenshi.com/catalog/g/gP-14977/ | ¥220 | ¥220 | FALSE | ¥220
C15,C17 | 2 | 10uF | Capacitor_SMD:C_1206_3216Metric_Pad1.33x1.80mm_HandSolder | https://akizukidenshi.com/catalog/g/gP-17338/ | ¥100 | ¥100 | FALSE | ¥100
R1,R2,R5,R6,R9,R14,R15,R16,R17,R18,R19,R20,R21,R22,R23,R24,R25,R26,R27,R28,R29,R45,R47,R49,R50,R51,R52,R53,R54,R55,R56,R57,R58,R59,R60,R61,R62,R63,R64 | 39 | 1kR | Resistor_SMD:R_0603_1608Metric_Pad0.98x0.95mm_HandSolder | https://www.chip1stop.com/view/dispDetail/DispDetail?partId=ROHM-0021097 | ¥100 | ¥100 | TRUE | ¥0
R4,R11 | 2 | 1MR | Resistor_SMD:R_0603_1608Metric_Pad0.98x0.95mm_HandSolder | https://www.chip1stop.com/view/dispDetail/DispDetail?partId=ROHM-0000199 | ¥100 | ¥100 | TRUE | ¥0
R32 | 1 | 3.3kR | Resistor_SMD:R_0603_1608Metric_Pad0.98x0.95mm_HandSolder | https://www.chip1stop.com/view/dispDetail/DispDetail?partId=ROHM-0039481 | ¥100 | ¥100 | TRUE | ¥0
R12,R13,R46,R48 | 4 | 5.1kR | Resistor_SMD:R_0603_1608Metric_Pad0.98x0.95mm_HandSolder | https://www.digikey.jp/ja/products/detail/yageo/RC0603FR-075K1L/727268 | ¥100 | ¥100 | FALSE | ¥100
R31 | 1 | 5.6kR | Resistor_SMD:R_0603_1608Metric_Pad0.98x0.95mm_HandSolder | https://www.chip1stop.com/view/dispDetail/DispDetail?partId=ROHM-0040168 | ¥100 | ¥100 | TRUE | ¥0
R3,R7,R8,R10,R30,R33,R34,TH1 | 8 | 10kR | Resistor_SMD:R_0603_1608Metric_Pad0.98x0.95mm_HandSolder | https://akizukidenshi.com/catalog/g/gP-05252/,https://www.chip1stop.com/view/dispDetail/DispDetail | ¥100 | ¥100 | TRUE | ¥0
R37 | 1 | 100R | Resistor_SMD:R_0603_1608Metric_Pad0.98x0.95mm_HandSolder | https://www.chip1stop.com/view/dispDetail/DispDetail?partId=ROHM-0021097 | ¥100 | ¥100 | TRUE | ¥0
R44 | 1 | 120R | Resistor_SMD:R_0603_1608Metric_Pad0.98x0.95mm_HandSolder | https://www.chip1stop.com/view/dispDetail/DispDetail?partId=ROHM-0040116 | ¥100 | ¥100 | TRUE | ¥0
R39,R42 | 2 | 0.1R2W | Resistor_SMD:R_2816_7142Metric_Pad3.20x4.45mm_HandSolder | https://www.chip1stop.com/view/dispDetail/DispDetail?partId=VISH-0652940 | ¥586 | ¥1172 | FALSE | ¥1172
R36 | 1 | 100kR+-1% | Resistor_SMD:R_0603_1608Metric_Pad0.98x0.95mm_HandSolder | https://www.chip1stop.com/view/dispDetail/DispDetail?partId=ROHM-0021098 | ¥100 | ¥100 | FALSE | ¥100
U11 | 1 | 24LC256 | Package_DIP:DIP-8_W7.62mm | https://akizukidenshi.com/catalog/g/gI-00705/ | ¥160 | ¥160 | FALSE | ¥160
FB1,FB2 | 2 | 2kR@100MHz | Inductor_SMD:L_0603_1608Metric_Pad1.05x0.95mm_HandSolder | https://www.digikey.jp/ja/products/detail/tdk/MMZ1608S202ATA00/3078624 | ¥100 | ¥200 | FALSE | ¥200
Q2 | 1 | 2SC3325-Y | Package_TO_SOT_SMD:SC-59_Handsoldering | https://akizukidenshi.com/catalog/g/gI-00628/ | ¥100 | ¥100 | TRUE | ¥0
R35 | 1 | 348kR ﾂｱ1% | Resistor_SMD:R_0603_1608Metric_Pad0.98x0.95mm_HandSolder | https://www.chip1stop.com/view/dispDetail/DispDetail?partId=ROHM-0021098 | ¥100 | ¥100 | FALSE | ¥100
U10 | 1 | ADM2582E | Package_SO:SOIC-20W_7.5x12.8mm_P1.27mm | https://www.analog.com/media/en/technical-documentation/data-sheets/adm2582e-2587e.pdf | ¥2986 | ¥2986 | FALSE | ¥2986
U1 | 1 | ATmega2560-16A | Package_QFP:TQFP-100_14x14mm_P0.5mm | https://akizukidenshi.com/catalog/g/g116567/ | ¥2800 | ¥2800 | FALSE | ¥2800
J11 | 1 | CONN_AUDIO | TerminalBlock_WAGO:TerminalBlock_WAGO_2601-3102_1x02_P3.50mm_Vertical | https://www.digikey.jp/ja/products/detail/wago-corporation/2601-3102/17125194 | ¥401 | ¥401 | FALSE | ¥401
J8 | 1 | CONN_BOARD_3 | TSRP_Connector_Hirose:DF51A-6DP-2DSA | ~ | ¥0 | ¥0 |  | ¥0
J1 | 1 | CONN_ICSP | Connector_PinHeader_2.54mm:PinHeader_1x06_P2.54mm_Vertical | ~ | ¥0 | ¥0 |  | ¥0
J9 | 1 | CONN_PANEL_BAORD_1 | TSRP_Connector_Hirose:DF51A-18DP-2DS | ~ | ¥0 | ¥0 |  | ¥0
J10 | 1 | CONN_PANEL_BAORD_2 | TSRP_Connector_Hirose:DF51A-22DP-2DS | ~ | ¥0 | ¥0 |  | ¥0
J13 | 1 | CONN_RS485 | TerminalBlock_WAGO:TerminalBlock_WAGO_2601-3104_1x04_P3.50mm_Vertical | https://www.digikey.jp/ja/products/detail/wago-corporation/2601-3104/17121801 | ¥750 | ¥750 | FALSE | ¥750
J12 | 1 | CONN_SPEAKER | TerminalBlock_WAGO:TerminalBlock_WAGO_2601-3102_1x02_P3.50mm_Vertical | https://www.digikey.jp/ja/products/detail/wago-corporation/2601-3102/17125194 | ¥401 | ¥401 | FALSE | ¥401
J7 | 1 | CONN_STATUS_PANEL | TSRP_Connector_Hirose:DF51A-14DP-2DS | ~ | ¥0 | ¥0 |  | ¥0
J2 | 1 | CONN_USB | TerminalBlock_WAGO:TerminalBlock_WAGO_2601-3104_1x04_P3.50mm_Vertical | https://www.digikey.jp/ja/products/detail/wago-corporation/2601-3104/17121801 | ¥750 | ¥750 | FALSE | ¥750
J6 | 1 | DC_IN | TerminalBlock_WAGO:TerminalBlock_WAGO_2601-3102_1x02_P3.50mm_Vertical | https://www.digikey.jp/ja/products/detail/wago-corporation/2601-3102/17125194 | ¥401 | ¥401 | FALSE | ¥401
U9 | 1 | DFPlayer | TSRP_Module:DFPlayer-mini | https://akizukidenshi.com/catalog/g/gM-12544/ | ¥1050 | ¥1050 | TRUE | ¥0
J5 | 1 | FROM_CONVERTER | TerminalBlock_WAGO:TerminalBlock_WAGO_2601-3102_1x02_P3.50mm_Vertical | https://www.digikey.jp/ja/products/detail/wago-corporation/2601-3102/17125194 | ¥401 | ¥401 | FALSE | ¥401
U2 | 1 | FT232RNL | Package_SO:SSOP-28_5.3x10.2mm_P0.65mm | https://akizukidenshi.com/catalog/g/g118243/ | ¥550 | ¥550 | FALSE | ¥550
D1,D3,D5 | 3 | GS1010FL | Diode_SMD:D_SOD-123F | https://akizukidenshi.com/catalog/g/gI-06014/ | ¥100 | ¥300 | FALSE | ¥300
Y1 | 1 | HUSG-16.000-20 | Crystal:Crystal_HC49-4H_Vertical | https://akizukidenshi.com/catalog/g/gP-08671/ | ¥30 | ¥30 | FALSE | ¥30
U6,U7 | 2 | INA219BIDCNT | Package_TO_SOT_SMD:SOT-23-8 | https://www.chip1stop.com/view/dispDetail/DispDetail?partId=TI01-0202709 | ¥481 | ¥962 | FALSE | ¥962
D6,D8 | 2 | LED_B | LED_SMD:LED_0603_1608Metric_Pad1.05x0.95mm_HandSolder | https://akizukidenshi.com/catalog/g/gI-03982/ | ¥100 | ¥200 | FALSE | ¥200
D12,D14 | 2 | LED_G | LED_SMD:LED_0603_1608Metric_Pad1.05x0.95mm_HandSolder | https://akizukidenshi.com/catalog/g/gI-06417/ | ¥100 | ¥200 | FALSE | ¥200
D2,D7,D9,D10,D15,D16,D17,D18,D19,D20,D21,D22,D23,D24,D25 | 15 | LED_O | LED_SMD:LED_0603_1608Metric_Pad1.05x0.95mm_HandSolder | https://akizukidenshi.com/catalog/g/g130072/,https://akizukidenshi.com/catalog/g/gI-06416/ | ¥100 | ¥100 | FALSE | ¥100
D11,D13 | 2 | LED_R | LED_SMD:LED_0603_1608Metric_Pad1.05x0.95mm_HandSolder | https://akizukidenshi.com/catalog/g/gI-03978/ | ¥100 | ¥200 | FALSE | ¥200
D4 | 1 | LED_Y | LED_SMD:LED_0603_1608Metric_Pad1.05x0.95mm_HandSolder | https://akizukidenshi.com/catalog/g/g111880 | ¥100 | ¥100 | FALSE | ¥100
F1 | 1 | MF-NSMF050 | Fuse:Fuse_1206_3216Metric_Pad1.42x1.75mm_HandSolder | https://akizukidenshi.com/catalog/g/gP-15300/ | ¥110 | ¥110 | TRUE | ¥0
U5 | 1 | NJM7805SDL1 | Package_TO_SOT_SMD:TO-252-2 | https://akizukidenshi.com/catalog/g/gI-11237/ | ¥50 | ¥50 | TRUE | ¥0
SW1,SW2,SW3 | 3 | SW_Push | TSRP_Button_Switch_SMD:SKRPACE010 | https://akizukidenshi.com/catalog/g/g106185/ | ¥100 | ¥100 | TRUE | ¥0
SW4,SW5,SW6,SW7,SW8,SW9,SW10,SW11,SW12,SW13,SW14,SW15,SW16,SW17 | 14 | SW_Push | Connector_PinHeader_2.54mm:PinHeader_1x02_P2.54mm_Vertical | https://akizukidenshi.com/catalog/g/gC-08593/ | ¥25 | ¥25 | FALSE | ¥25
Q1,Q3 | 2 | TJ8S06M3L | Package_TO_SOT_SMD:TO-252-2 | https://akizukidenshi.com/catalog/g/gI-13964/ | ¥60 | ¥120 | FALSE | ¥120
J4 | 1 | TO_CONVERTER | TerminalBlock_WAGO:TerminalBlock_WAGO_2601-3102_1x02_P3.50mm_Vertical | https://www.digikey.jp/ja/products/detail/wago-corporation/2601-3102/17125194 | ¥401 | ¥401 | FALSE | ¥401
TP3 | 1 | TP_5V | TestPoint:TestPoint_THTPad_D2.5mm_Drill1.2mm | https://akizukidenshi.com/catalog/g/gP-12215/ | ¥30 | ¥30 | TRUE | ¥0
TP2 | 1 | TP_12V | TestPoint:TestPoint_THTPad_D2.5mm_Drill1.2mm | https://akizukidenshi.com/catalog/g/gP-12215/ | ¥30 | ¥30 | TRUE | ¥0
TP4 | 1 | TP_GND | TestPoint:TestPoint_THTPad_D2.5mm_Drill1.2mm | https://akizukidenshi.com/catalog/g/gP-12215/ | ¥30 | ¥30 | TRUE | ¥0
TP1 | 1 | TP_INPUT | TestPoint:TestPoint_THTPad_D2.5mm_Drill1.2mm | https://akizukidenshi.com/catalog/g/gP-12215/ | ¥30 | ¥30 | TRUE | ¥0
U4 | 1 | TPS2116DRL | Package_TO_SOT_SMD:SOT-583-8 | https://www.ti.com/lit/ds/symlink/tps2116.pdf | ¥149 | ¥149 | FALSE | ¥149
C20,C21 | 2 | uF | Capacitor_SMD:C_0603_1608Metric_Pad1.08x0.95mm_HandSolder | ~ | ¥0 | ¥0 | TRUE | ¥0
J3 | 1 | USB_C_Receptacle_USB2.0_16P | Connector_USB:USB_C_Receptacle_GCT_USB4105-xx-A_16P_TopMnt_Horizontal | https://akizukidenshi.com/catalog/g/g114356/ | ¥110 | ¥110 | FALSE | ¥110
U3 | 1 | USBLC6-2SC6 | Package_TO_SOT_SMD:SOT-23-6 | https://www.st.com/resource/en/datasheet/usblc6-2.pdf | ¥60 | ¥60 | FALSE | ¥60

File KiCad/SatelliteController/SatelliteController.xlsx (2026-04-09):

Reference | Value | Footprint | Qty | DNP | 購入可否 | TRUE
C1,C2 | 15pF | Capacitor_SMD:C_0603_1608Metric_Pad1.08x0.95mm_HandSolder | 2 |  | FALSE | FALSE
C3,C4,C5,C6,C7,C8,C9,C10,C11,C13,C15,C16,C17,C18 | 0.1uF | Capacitor_SMD:C_0603_1608Metric_Pad1.08x0.95mm_HandSolder | 14 |  | FALSE
C12,C14 | 10uF | Capacitor_SMD:C_1206_3216Metric_Pad1.33x1.80mm_HandSolder | 2 |  | TRUE
D1,D5,D27,D28,D29,D30,D31,D32,D33,D34,D35 | GS1010FL | Diode_SMD:D_SOD-123F | 11 |  | FALSE
D2,D9,D11,D12,D17,D18,D19,D20,D21,D22,D23,D24,D25,D26 | LED_O | LED_SMD:LED_0603_1608Metric_Pad1.05x0.95mm_HandSolder | 14 |  | FALSE
D3,D4 | SMAJ45A | Diode_SMD:D_SMA_Handsoldering | 2 |  | FALSE
D6,D7 | SS2040FL | Diode_SMD:D_SOD-123F | 2 |  | FALSE
D8,D10 | LED_B | LED_SMD:LED_0603_1608Metric_Pad1.05x0.95mm_HandSolder | 2 |  | FALSE
D13,D15 | LED_R | LED_SMD:LED_0603_1608Metric_Pad1.05x0.95mm_HandSolder | 2 |  | FALSE
D14,D16 | LED_G | LED_SMD:LED_0603_1608Metric_Pad1.05x0.95mm_HandSolder | 2 |  | FALSE
F1 | MF-NSMF050 | Fuse:Fuse_1206_3216Metric_Pad1.42x1.75mm_HandSolder | 1 |  | TRUE
J1 | CONN_ICSP | Connector_PinSocket_2.54mm:PinSocket_1x06_P2.54mm_Vertical | 1 |  | FALSE
J2 | CONN_USB | TSRP_TerminalBlock_Alphaplus:TB401-1-4-E | 1 |  | FALSE
J3 | USB_B_Micro | Connector_USB:USB_Micro-B_Wuerth_629105150521 | 1 |  | FALSE
J4 | TO_CONVERTER | TSRP_TerminalBlock_Alphaplus:TB411-2-2-E-1 | 1 |  | FALSE
J5 | FROM_CONVERTER | TSRP_TerminalBlock_Alphaplus:TB411-2-2-E-1 | 1 |  | FALSE
J6 | DC_IN | TSRP_TerminalBlock_Alphaplus:TB411-2-2-E-1 | 1 |  | FALSE
J7 | CONN_STATUS_PANEL | TSRP_Connector_Hirose:DF51A-14DP-2DS | 1 |  | FALSE
J8 | CONN_PANEL_BAORD_2 | TSRP_Connector_Hirose:DF51A-22DP-2DS | 1 |  | FALSE
J9 | CONN_RS485 | TSRP_TerminalBlock_Alphaplus:TB401-1-4-E | 1 |  | FALSE
J10 | CONN_N2O_PRESS | TSRP_TerminalBlock_Alphaplus:TB401-1-4-E | 1 |  | FALSE
J11 | CONN_UMBILICAL | TSRP_TerminalBlock_Alphaplus:TB401-1-4-E | 1 |  | FALSE
J12 | RELAY_POWER | TSRP_TerminalBlock_Alphaplus:TB411-2-2-E-1 | 1 |  | FALSE
J13 | IGNITOR | TSRP_TerminalBlock_Alphaplus:TB411-2-2-E-1 | 1 |  | FALSE
J14 | CONN_SORENOID_VALVE | TSRP_Connector_Hirose:DF51A-8DP-2DS | 1 |  | FALSE
L1 | 10uH | Inductor_SMD:L_1210_3225Metric_Pad1.42x2.65mm_HandSolder | 1 |  | TRUE
Q1,Q3 | TJ8S06M3L | Package_TO_SOT_SMD:TO-252-2 | 2 |  | TRUE
Q2 | 2SC3325-Y | Package_TO_SOT_SMD:SC-59_Handsoldering | 1 |  | FALSE
Q4,Q5,Q6,Q7,Q8,Q9,Q10,Q11,Q12,Q13 | AO3400A | Package_TO_SOT_SMD:SOT-23 | 10 |  | FALSE
R1,R5,R7,R8,R14,R15,R16,R19,R20,R21,R22,R50,R52,R56,R58,R60,R68,R70,R76,R78,R80,TH1 | 10kR | Resistor_SMD:R_0603_1608Metric_Pad0.98x0.95mm_HandSolder | 22 |  | FALSE
R2 | 1MR | Resistor_SMD:R_0603_1608Metric_Pad0.98x0.95mm_HandSolder | 1 |  | TRUE
R3,R4,R6,R11,R27,R29,R31,R32,R34,R36,R37,R38,R39,R40,R41,R42,R43,R44,R45,R46,R47,R48 | 1kR | Resistor_SMD:R_0603_1608Metric_Pad0.98x0.95mm_HandSolder | 22 |  | FALSE
R9,R10 | 22R | Resistor_SMD:R_0603_1608Metric_Pad0.98x0.95mm_HandSolder | 2 |  | FALSE
R12 | 5.6kR | Resistor_SMD:R_0603_1608Metric_Pad0.98x0.95mm_HandSolder | 1 |  | FALSE
R13 | 3.3kR | Resistor_SMD:R_0603_1608Metric_Pad0.98x0.95mm_HandSolder | 1 |  | FALSE
R17,R18 | 0.1R2W | Resistor_SMD:R_2816_7142Metric_Pad3.20x4.45mm_HandSolder | 2 |  | FALSE
R23,R49,R51,R55,R57,R59,R67,R69,R75,R77,R79 | 120R | Resistor_SMD:R_0603_1608Metric_Pad0.98x0.95mm_HandSolder | 11 |  | FALSE
R24 | 240R | Resistor_SMD:R_0603_1608Metric_Pad0.98x0.95mm_HandSolder | 1 |  | FALSE
R25,R26 | 300R | Resistor_SMD:R_0603_1608Metric_Pad0.98x0.95mm_HandSolder | 2 |  | FALSE
R28 | 3.6kR | Resistor_SMD:R_0603_1608Metric_Pad0.98x0.95mm_HandSolder | 1 |  | FALSE
R30 | 2.4kR | Resistor_SMD:R_0603_1608Metric_Pad0.98x0.95mm_HandSolder | 1 |  | FALSE
R33,R35 | 2.2kR | Resistor_SMD:R_0603_1608Metric_Pad0.98x0.95mm_HandSolder | 2 |  | FALSE
R53,R61,R63,R65,R71,R73,R81,R83 | 56kR | Resistor_SMD:R_0603_1608Metric_Pad0.98x0.95mm_HandSolder | 8 |  | FALSE
R54,R62,R64,R66,R72,R74,R82,R84 | 33kR | Resistor_SMD:R_0603_1608Metric_Pad0.98x0.95mm_HandSolder | 8 |  | FALSE
SW1,SW2,SW3,SW4 | SW_Push | Connector_PinHeader_2.54mm:PinHeader_1x02_P2.54mm_Vertical,TSRP_Button_Switch_SMD:TVAF06-A020B-R | 4 |  | FALSE
TP1 | TP_INPUT | TestPoint:TestPoint_THTPad_D2.5mm_Drill1.2mm | 1 |  | FALSE
TP2 | TP_12V | TestPoint:TestPoint_THTPad_D2.5mm_Drill1.2mm | 1 |  | FALSE
TP3 | TP_5V | TestPoint:TestPoint_THTPad_D2.5mm_Drill1.2mm | 1 |  | FALSE
TP4 | TP_GND | TestPoint:TestPoint_THTPad_D2.5mm_Drill1.2mm | 1 |  | FALSE
U1 | ATMEGA2560-16AUR | Package_QFP:TQFP-100_14x14mm_P0.5mm | 1 |  | FALSE
U2 | FT232RL | Package_SO:SSOP-28_5.3x10.2mm_P0.65mm | 1 |  | FALSE
U3 | NJM7805SDL1 | Package_TO_SOT_SMD:TO-252-2 | 1 |  | FALSE
U4,U5 | INA219BIDCNT | Package_TO_SOT_SMD:SOT-23-8 | 2 |  | FALSE
U6 | LTC485CN8#PBF | Package_DIP:DIP-8_W7.62mm | 1 |  | FALSE
U7,U8 | TLP785F | Package_DIP:DIP-4_W10.16mm | 2 |  | FALSE
U9 | MCP3208 | Package_DIP:DIP-16_W7.62mm | 1 |  | FALSE
Y1 | HUSG-16.000-20 | Crystal:Crystal_HC49-U_Vertical | 1 |  | FALSE

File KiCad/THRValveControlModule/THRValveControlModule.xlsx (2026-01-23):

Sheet: THRValveControlModule
在庫フラグ | Reference | Qty | Value | Footprint | Datasheet | Supplyer | 単価
購入 | U2 | 1 | ICM-42688 | TSRP_IC:StrawberryLinux_ICM-42688-P | https://strawberry-linux.com/pub/icm-42688-manual.pdf | https://strawberry-linux.com/catalog/items?code=42688 | ¥1320 | ¥1320
〇 | U6 | 1 | SC8721 | TSRP_IC:StrawberryLinux_SC8721 | https://strawberry-linux.com/pub/sc8721-manual.pdf | https://strawberry-linux.com/catalog/items?code=18721 | ¥1100 | ¥1100
〇 | U3 | 1 | ADXL375 | TSRP_IC:StrawberryLinux_ADXL375 | https://strawberry-linux.com/pub/adxl375-manual.pdf | https://strawberry-linux.com/catalog/items?code=12112 | ¥2354 | ¥2354
購入 | U1 | 1 | XIAO-RA4M1-SMD | TSRP_Seeed_XIAO:XIAO-RA4M1-SMD | https://wiki.seeedstudio.com/ja/getting_started_xiao_ra4m1/ | https://akizukidenshi.com/catalog/g/g131171/ | ¥1100 | ¥1100
購入 | U4 | 1 | ATA6561 | Package_SO:SOIC-8_3.9x4.9mm_P1.27mm | https://akizukidenshi.com/goodsaffix/ATA6560_1.pdf | https://akizukidenshi.com/catalog/g/g130008/ | ¥60 | ¥60
購入 | D2 | 1 | P4KE15A | Diode_THT:D_DO-41_SOD81_P2.54mm_Vertical_KathodeUp | https://akizukidenshi.com/goodsaffix/P4KE.pdf | https://akizukidenshi.com/catalog/g/g129635/ | ¥180 | ¥180
購入 | J4 | 1 | XT30PW-M | Connector_AMASS:AMASS_XT30PW-M_1x02_P2.50mm_Horizontal | https://akizukidenshi.com/goodsaffix/XT30PW-M.pdf | https://akizukidenshi.com/catalog/g/g117949/ | ¥70 | ¥70
購入 | D6 | 1 | 1N4148W | Diode_SMD:D_SOD-123 | https://www.vishay.com/docs/85748/1n4148w.pdf | https://akizukidenshi.com/catalog/g/g116985/ | ¥160 | ¥160
購入 | U5 | 1 | MAX485E | Package_SO:SOIC-8_3.9x4.9mm_P1.27mm | https://datasheets.maximintegrated.com/en/ds/MAX1487E-MAX491E.pdf | https://akizukidenshi.com/catalog/g/g116568/ | ¥160 | ¥160
〇 | U8,U9 | 2 | TC7S14F | Package_TO_SOT_SMD:SOT-23-5 | https://www.ti.com/lit/ds/symlink/sn74lvc1g14.pdf | https://akizukidenshi.com/catalog/g/g114737/ | ¥60 | ¥120
〇 | C18 | 1 | 0.1uF | Capacitor_SMD:C_0603_1608Metric_Pad1.08x0.95mm_HandSolder | https://akizukidenshi.com/catalog/g/g113374/ | https://akizukidenshi.com/catalog/g/g113374/ | ¥100 | ¥100
購入 | J1 | 1 | B4B-XH-A(LF)(SN) | Connector_JST:JST_XH_B4B-XH-A_1x04_P2.50mm_Vertical | https://akizukidenshi.com/goodsaffix/xh.pdf | https://akizukidenshi.com/catalog/g/g112249/ | ¥10 | ¥10
購入 | J2,J3 | 2 | B3B-XH-A(LF)(SN) | Connector_JST:JST_XH_B3B-XH-A_1x03_P2.50mm_Vertical | https://akizukidenshi.com/goodsaffix/xh.pdf | https://akizukidenshi.com/catalog/g/g112248/ | ¥10 | ¥20
〇 | J6 | 1 | SSD1306 | Connector_PinHeader_2.54mm:PinHeader_1x04_P2.54mm_Vertical | https://akizukidenshi.com/goodsaffix/ssd1306.pdf | https://akizukidenshi.com/catalog/g/g112031/ | ¥580 | ¥580
購入 | U7 | 1 | BP5293-50 | TSRP_IC:BP5293-50 | https://akizukidenshi.com/goodsaffix/BP5293_DataSheet_J_VerC_161013.pdf | https://akizukidenshi.com/catalog/g/g111188/ | ¥240 | ¥240
購入 | LS1 | 1 | UGCT7525AN4 | TSRP_Speaker:UGCT7525AN4 | https://akizukidenshi.com/goodsaffix/UGCT7525AN4.pdf | https://akizukidenshi.com/catalog/g/g109801/ | ¥100 | ¥100
〇 | SW2 | 1 | SKRPACE010 | TSRP_Button_Switch_SMD:SKRPACE010 | https://tech.alpsalpine.com/prod/j/html/tact/surfacemount/skrp/skrpace010.html | https://akizukidenshi.com/catalog/g/g106185/ | ¥100 | ¥100
購入 | Q1 | 1 | IRLML6344TRPBFTR | Package_TO_SOT_SMD:SOT-23_Handsoldering | https://akizukidenshi.com/goodsaffix/irlml6344pbf.pdf | https://akizukidenshi.com/catalog/g/g106049/ | ¥330 | ¥330
購入 | C4 | 1 | 1000u | Capacitor_THT:CP_Radial_D12.5mm_P5.00mm | https://akizukidenshi.com/goodsaffix/zlh.pdf | https://akizukidenshi.com/catalog/g/g102722/ | ¥60 | ¥60
購入 | SW1 | 1 | IS-2235 | Button_Switch_THT:SW_CK_JS202011CQN_DPDT_Straight | https://akizukidenshi.com/goodsaffix/IS-2235-G_20191212.pdf | https://akizukidenshi.com/catalog/g/g102627/ | ¥110 | ¥110
購入 | D5 | 1 | MA10EB045 | TSRP_Diode:MA_DO-221BC | https://akizukidenshi.com/goodsaffix/MA10EB045-file.pdf | https://akizukidenshi.com/catalog/g/g117496/ | ¥150 | ¥150
購入 | D1 | 1 | RB160M-30TR | Diode_SMD:D_SOD-123 | https://akizukidenshi.com/goodsaffix/RB160M-30_j.pdf | https://akizukidenshi.com/catalog/g/g101398/ | ¥150 | ¥150
〇 | U10 | 1 | MB85RQ8MX | Package_SO:SOIC-16W_7.5x10.3mm_P1.27mm | https://www.ramxeed.com/jp/home/wp-content/uploads/2024/12/MB85RQ8MX-DS1v1-J.pdf |  |  | ¥0
〇 | R9 | 1 | 1k | Resistor_SMD:R_0603_1608Metric_Pad0.98x0.95mm_HandSolder | ~ |  |  | ¥0
〇 | R5,R6 | 2 | 120 | Resistor_SMD:R_0603_1608Metric_Pad0.98x0.95mm_HandSolder | ~ |  |  | ¥0
〇 | R3,R4 | 2 | 4.7k | Resistor_SMD:R_0603_1608Metric_Pad0.98x0.95mm_HandSolder | ~ |  |  | ¥0
〇 | R1,R2,R7,R8,R10,R11,R12,R13,R15 | 9 | 10k | Resistor_SMD:R_0603_1608Metric_Pad0.98x0.95mm_HandSolder | ~ |  |  | ¥0
〇 | J7 | 1 | DF51A-8DP-2DS | TSRP_Connector_Hirose:DF51A-8DP-2DS | https://www.hirose.com/ja/product/p/CL0543-5059-0-20 |  |  | ¥0
〇 | J5 | 1 | DF51A-4P-2DSA | TSRP_Connector_Hirose:DF51A-4P-2DSA | https://www.hirose.com/ja/product/p/CL0543-5107-0-00 |  |  | ¥0
〇 | H1,H2,H3,H4 | 4 | MountingHole |  |  |  |  | ¥0
〇 | C1,C2,C6,C7,C8,C9 | 6 | 0.1u | Capacitor_SMD:C_0603_1608Metric_Pad1.08x0.95mm_HandSolder | ~ |  | 合計 | ¥8574

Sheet: Sheet1
〇
✕
購入

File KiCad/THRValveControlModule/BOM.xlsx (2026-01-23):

No. | 型番 | 単価 | 購入場所 | URL | 備考
1 | ICM-42688 | ¥1320 | ストロベリーリナックス | https://strawberry-linux.com/catalog/items?code=42688
2 | SC8721 | ¥1100 | ストロベリーリナックス | https://strawberry-linux.com/catalog/items?code=18721
3 | XT30PW-M | ¥70 | 秋月電子 | https://akizukidenshi.com/catalog/g/g117949/
4 | MAX485ED | ¥160 | 秋月電子 | https://akizukidenshi.com/catalog/g/g116568
5 | IS-2235 | ¥110 | 秋月電子 | https://akizukidenshi.com/catalog/g/g102627/
6 | SSD1306 | ¥580 | 秋月電子 | https://akizukidenshi.com/catalog/g/g112031/
7 | ADXL375 | ¥2354 | ストロベリーリナックス | https://strawberry-linux.com/catalog/items?code=12112
8 | B4B-XH-A(LF)(SN) | ¥10 | 秋月電子 | https://akizukidenshi.com/catalog/g/g112249/
9 | SK54 | ¥200 | 秋月電子 | https://akizukidenshi.com/catalog/g/g104128/
10 | 35ZLH470MEFC10X16 | ¥40 | 秋月電子 | https://akizukidenshi.com/catalog/g/g102719/
11 | 102010551 | ¥1100 | 秋月電子 | https://akizukidenshi.com/catalog/g/g131171/ | Seeed XIAO RA4M1
12 | MA10EB045 | ¥80 | 秋月電子 | https://akizukidenshi.com/catalog/g/g117496/
13 | RB160M-30TR | ¥150 | 秋月電子 | https://akizukidenshi.com/catalog/g/g101398/
14 | BP5293-50 | ¥240 | 秋月電子 | https://akizukidenshi.com/catalog/g/g111188/
15 | IS-2235 | ¥110 | 秋月電子 | https://akizukidenshi.com/catalog/g/g102627/
16 | TC7S14F | ¥60 | 秋月電子 | https://akizukidenshi.com/catalog/g/g114737/
17
18
19
20
合計 |  | ¥7684

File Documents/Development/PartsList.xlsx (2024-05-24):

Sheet: Build４
品名 | 記号 | 型番 | 購入先 | 通販コード | 単価 | セット個数 | 必要個数 | 在庫個数 | 購入数 (パック数) | 価格 | 備考 | URL
チップ積層セラミックコンデンサー 15pF50V NP0 1608 | C1, C2 | CC0603N150J500 | 秋月電子通商 | 113312 | ¥100.00 | 40 | 2 | 64 | 0 | ¥0.00 |  | https://akizukidenshi.com/catalog/g/g113312/
チップ積層セラミックコンデンサー 0.1μF50V X8L 1608 | C3-C11, C13, C15-C18 | GCM188L81H104K57 | 秋月電子通商 | 116143 | ¥110.00 | 40 | 14 | 18 | 0 | ¥0.00 |  | https://akizukidenshi.com/catalog/g/g116143/
チップ積層セラミックコンデンサー 10μF50V B 3216 | C12, C14 | GRM31CB31H106KA12 | 秋月電子通商 | 117338 | ¥250.00 | 10 | 2 | 4 | 0 | ¥0.00 |  | https://akizukidenshi.com/catalog/g/g117338/
チップダイオード 1000V1A GS1010FL | D1, D5, D27-D35 | GS1010FL | 秋月電子通商 | 106014 | ¥100.00 | 10 | 11 | 7 | 1 | ¥100.00 |  | https://akizukidenshi.com/catalog/g/g106014/
黄色チップLED [1608] OSYL1608 | D2, D9, D11, D12, D17-D26 | OSYL1608C1A | 秋月電子通商 | 103984 | ¥200.00 | 20 | 14 | 42 | 0 | ¥0.00 |  | https://akizukidenshi.com/catalog/g/g103984/
TVSダイオード(サージ吸収素子) SMAJ45A | D3, D4 | SMAJ45A | 秋月電子通商 | 107409 | ¥120.00 | 20 | 2 | 8 | 0 | ¥0.00 |  | https://akizukidenshi.com/catalog/g/g107409/
表面実装用ショットキーバリアダイオード 40V2A SS2040FL | D6, D7 | SS2040FL | 秋月電子通商 | 102073 | ¥480.00 | 20 | 2 | 8 | 0 | ¥0.00 |  | https://akizukidenshi.com/catalog/g/g102073/
青色チップLED [1608] OSBL1608 | D8, D10 | OSBL1608C1A | 秋月電子通商 | 103982 | ¥200.00 | 20 | 2 | 36 | 0 | ¥0.00 |  | https://akizukidenshi.com/catalog/g/g103982/
赤色チップLED [1608] 625nm 120度 OSHR1608 | D13, D15 | OSHR1608C1A | 秋月電子通商 | 103978 | ¥200.00 | 20 | 2 | 5 | 0 | ¥0.00 |  | https://akizukidenshi.com/catalog/g/g103978/
黄緑色チップLED [1608] OSYG1608 | D14, D16 | OSYG1608C1A | 秋月電子通商 | 103980 | ¥200.00 | 20 | 2 | 3 | 0 | ¥0.00 |  | https://akizukidenshi.com/catalog/g/g103980/
リセッタブルヒューズ 0.5A トリップ電流:1A 耐圧:13.2V | F1 | MF-NSMF050-2 | 秋月電子通商 | 115300 | ¥100.00 | 4 | 1 | 6 | 0 | ¥0.00 |  | https://akizukidenshi.com/catalog/g/g115300/
ピンソケット(メス) 1×6(6P) | J1 | FH-1x6SG/RH | 秋月電子通商 | 103784 | ¥20.00 | 1 | 1 | 1 | 0 | ¥0.00 |  | https://akizukidenshi.com/catalog/g/g103784/
ターミナルブロック 2.54mm 4P 緑 縦 | J2, J9-J11 | TB401-1-4-E | 秋月電子通商 | 107756 | ¥80.00 | 1 | 4 | 0 | 4 | ¥320.00 |  | https://akizukidenshi.com/catalog/g/g107756/
Wurth Elektronik 629105150521 | J3 | 629105150521 | マウザー | 710-629105150521 | ¥338.00 | 1 | 1 | 4 | 0 | ¥0.00 |  | https://mou.sr/3JVSi6N
ターミナルブロック 2P 緑 縦 | J4-J6, J12, J13 | TB411-2-2-E-1 | 秋月電子通商 | 106309 | ¥50.00 | 1 | 5 | 0 | 5 | ¥250.00 |  | https://akizukidenshi.com/catalog/g/g106309/
Hirose Connector DF51A-14DP-2DS(20) | J7 | DF51A-14DP-2DS(20) | マウザー | 798-DF51A14DP2DS20 | ¥165.00 | 1 | 1 | 0 | 1 | ¥165.00 |  | https://mou.sr/4brxvUl
Hirose Connector DF51A-22DP-2DS(20) | J8 | DF51A-22DP-2DS(20) | マウザー | 798-DF51A22DP2DS20 | ¥225.00 | 1 | 1 | 0 | 1 | ¥225.00 |  | https://mou.sr/4bJuMWN
Hirose Connector DF51A-8DP-2DS(20) | J14 | DF51A-8DP-2DS(20) | マウザー | 798-DF51A-8DP2DS(20) | ¥119.00 | 1 | 1 | 0 | 1 | ¥119.00 |  | https://mou.sr/4dRehJu
チップインダクター 10μH1.1A | L1 | DFE322512F-100M | 秋月電子通商 | 114977 | ¥220.00 | 5 | 1 | 4 | 0 | ¥0.00 |  | https://akizukidenshi.com/catalog/g/g114977/
PchパワーMOSFET 60V8A TJ8S06M3L | Q1, Q3 | TJ8S06M3L(T6L1NQ) | 秋月電子通商 | 113964 | ¥60.00 | 1 | 2 | 4 | 0 | ¥0.00 |  | https://akizukidenshi.com/catalog/g/g113964/
チップトランジスタ 2SC3325-Y 50V500mA | Q2 | 2SC3325-Y | 秋月電子通商 | 100628 | ¥100.00 | 20 | 1 | 28 | 0 | ¥0.00 |  | https://akizukidenshi.com/catalog/g/g100628/
NchパワーMOSFET 30V5.7A AO3400A | Q4-Q13 | AO3400A | 秋月電子通商 | 114653 | ¥220.00 | 10 | 10 | 0 | 2 | ¥440.00 |  | https://akizukidenshi.com/catalog/g/g114653/
Vishay / Dale CRCW060310K0FKEA | R1, R5, R7, R8, R14-R16, R19-R22, R50, R52, R56, R58, R60, R68, R70, R76, R78, R80, TH1 | CRCW060310K0FKEA | マウザー | 71-CRCW0603-10K-E3 | ¥150.00 | 100 | 22 | 99 | 0 | ¥0.00 |  | https://mou.sr/3VcHpUn
Vishay / Dale CRCW06031M00FKEC | R2 | CRCW06031M00FKEC | マウザー | 71-CRCW06031M00FKEC | ¥150.00 | 100 | 1 | 99 | 0 | ¥0.00 |  | https://mou.sr/44TU8hS
Vishay / Dale CRCW06031K00FKEA | R3, R4, R6, R11, R27, R29, R31, R32, R34, R36-R48 | CRCW06031K00FKEA | マウザー | 71-CRCW0603-1.0K-E3 | ¥150.00 | 100 | 22 | 99 | 0 | ¥0.00 |  | https://mou.sr/3VaIFXZ
Vishay / Dale CRCW060322R0FKEA | R9, R10 | CRCW060322R0FKEA | マウザー | 71-CRCW0603-22-E3 | ¥150.00 | 100 | 2 | 99 | 0 | ¥0.00 |  | https://mou.sr/3V8Xjz0
Vishay / Dale CRCW06035K60FKEA | R12 | CRCW06035K60FKEA | マウザー | 71-CRCW0603-5.6K-E3 | ¥150.00 | 100 | 1 | 99 | 0 | ¥0.00 |  | https://mou.sr/4bM06n8
Vishay / Dale CRCW06033K30FKEA | R13 | CRCW06033K30FKEA | マウザー | 71-CRCW0603-3.3K-E3 | ¥150.00 | 100 | 1 | 99 | 0 | ¥0.00 |  | https://mou.sr/3KibtaR
Vishay / Dale WSL2816R1000FEH | R17, R18 | WSL2816R1000FEH | マウザー | 71-WSL2816R1000FEH | ¥138.00 | 1 | 2 | 8 | 0 | ¥0.00 |  | https://mou.sr/4bR502u
Vishay / Dale CRCW0603120RFKTA | R23, R49, R51, R55, R57, R59, R67, R69, R75, R77, R79 | CRCW0603120RFKTA | マウザー | 71-CRCW0603-120 | ¥470.00 | 100 | 11 | 99 | 0 | ¥0.00 |  | https://mou.sr/3WSvjRr
Vishay / Dale CRCW0603240RFKEA | R24 | CRCW0603240RFKEA | マウザー | 71-CRCW0603-240-E3 | ¥150.00 | 100 | 1 | 99 | 0 | ¥0.00 |  | https://mou.sr/4aCKL7j
Vishay / Dale CRCW0603300RFKEA | R25, R26 | CRCW0603300RFKEA | マウザー | 71-CRCW0603-300-E3 | ¥150.00 | 100 | 2 | 99 | 0 | ¥0.00 |  | https://mou.sr/4btqjY1
Vishay / Dale CRCW06033K60FKEA | R28 | CRCW06033K60FKEA | マウザー | 71-CRCW0603-3.6K-E3 | ¥150.00 | 100 | 1 | 99 | 0 | ¥0.00 |  | https://mou.sr/4bMOG2D
Vishay / Dale CRCW06032K40FKEA | R30 | CRCW06032K40FKEA | マウザー | 71-CRCW0603-2.4K-E3 | ¥150.00 | 100 | 1 | 99 | 0 | ¥0.00 |  | https://mou.sr/3yEcF5A
Vishay / Dale CRCW06032K20FKEA | R33, R35 | CRCW06032K20FKEA | マウザー | 71-CRCW0603-2.2K-E3 | ¥150.00 | 100 | 2 | 99 | 0 | ¥0.00 |  | https://mou.sr/4bMOOiD
Vishay / Dale CRCW060356K0FKEA | R53, R61, R63, R65, R71, R73, R81, R83 | CRCW060356K0FKEA | マウザー | 71-CRCW0603-56K-E3 | ¥150.00 | 100 | 8 | 99 | 0 | ¥0.00 |  | https://mou.sr/4bLNGvy
Vishay / Dale CRCW060333K0FKTA | R54, R62, R64, R66, R72, R74, R82, R84 | CRCW060333K0FKTA | マウザー | 71-CRCW0603-33K | ¥470.00 | 100 | 8 | 99 | 0 | ¥0.00 |  | https://mou.sr/4dJxrkq
表面実装用タクトスイッチ TVAF06-A020B-R | SW1, SW2, SW4 | TVAF06-A020B-R | 秋月電子通商 | 114888 | ¥110.00 | 5 | 3 | 1 | 1 | ¥110.00 |  | https://akizukidenshi.com/catalog/g/g114888/
ピンヘッダ 1×2 (2P) | SW3 | PH-1X2SG | 秋月電子通商 | 108593 | ¥25.00 | 10 | 1 | 7 | 0 | ¥0.00 |  | https://akizukidenshi.com/catalog/g/g108593/
チェック端子(テストポイント) TEST-8 | TP1-TP4 | TEST-8 | 秋月電子通商 | 112215 | ¥30.00 | 1 | 4 | 0 | 0 | ¥0.00 |  | https://akizukidenshi.com/catalog/g/g112215/
AVRマイコン ATMEGA2560-16AUR | U1 | ATMEGA2560-16AUR | 秋月電子通商 | 116567 | ¥2800.00 | 1 | 1 | 0 | 1 | ¥2800.00 |  | https://akizukidenshi.com/catalog/g/g116567/
USBシリアル変換IC FT232RL | U2 | FT232RL | 秋月電子通商 | 101739 | ¥550.00 | 1 | 1 | 0 | 1 | ¥550.00 |  | https://akizukidenshi.com/catalog/g/g101739/
三端子レギュレーター 5V1.5A TO-252 NJM7805SDL1 | U3 | NJM7805SDL1 | 秋月電子通商 | 111237 | ¥50.00 | 1 | 1 | 3 | 0 | ¥0.00 |  | https://akizukidenshi.com/catalog/g/g111237/
Texas Instruments INA219BIDCNT | U4, U5 | INA219BIDCNT | マウザー | 595-INA219BIDCNT | ¥456.00 | 1 | 2 | 4 | 0 | ¥0.00 |  | https://mou.sr/3KgxruR
RS485/RS422トランシーバ LTC485CN8#PBF | U6 | LTC485CN8#PBF | 秋月電子通商 | 102792 | ¥250.00 | 1 | 1 | 0 | 1 | ¥250.00 |  | https://akizukidenshi.com/catalog/g/g102792/
Toshiba TLP785(F) | U7, U8 | TLP785(F) | マウザー | 757-TLP785F | ¥95.00 | 1 | 2 | 0 | 2 | ¥190.00 |  | https://mou.sr/4dUYSI3
12bit 8ch ADコンバータ MCP3208-CI/P | U9 | MCP3208-CI/P | 秋月電子通商 | 100238 | ¥600.00 | 1 | 1 | 0 | 0 | ¥0.00 |  | https://akizukidenshi.com/catalog/g/g100238/
クリスタル(水晶発振子) 16MHz | Y1 | HUSG-16.000-20 | 秋月電子通商 | 108671 | ¥30.00 | 1 | 1 | 0 | 0 | ¥0.00 |  | https://akizukidenshi.com/catalog/g/g108671/

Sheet: Build3
品名 | 記号（ラ） | 記号（サ） | 型番 | 購入先 | 通販コード | 単価 | 必要個数 | 在庫個数 | 購入数 (パック数) | 価格 | 購入数 (パック数) | 価格 | 備考 | URL
12bit 8ch ADコンバータ MCP3208-CI/P |  | U9 | MCP3208-CI/P | 秋月電子通商 | I-00238 | ¥600.00 | 1 | 0 | 1 | ¥600.00 | 2 | ¥1200.00 |  | https://akizukidenshi.com/catalog/g/gI-00238/
AVRマイコン ATMEGA2560-16AUR | U2 | U2 | ATMEGA2560-16AUR | 秋月電子通商 | I-16567 | ¥2800.00 | 2 | 0 | 2 | ¥5600.00 | 4 | ¥11200.00 |  | https://akizukidenshi.com/catalog/g/gI-16567/
DF51A-14DP-2DS(20) | J7 | J7 | DF51A-14DP-2DS(20) | DigiKey | 26-DF51A-14DP-2DS(20)-ND | ¥172.00 | 2 | 4 | 0 | ¥0.00 | 0 | ¥0.00 |  | https://www.digikey.jp/short/8jtz5nh7
DF51A-18DP-2DS(20) | J9 |  | DF51A-18DP-2DS(20) | DigiKey | 26-DF51A-18DP-2DS(20)-ND | ¥211.00 | 1 | 3 | 0 | ¥0.00 | 0 | ¥0.00 |  | https://www.digikey.jp/short/m885hv22
DF51A-22DP-2DS(20) | J8 | J8 | DF51A-22DP-2DS(20) | DigiKey | 26-DF51A-22DP-2DS(20)-ND | ¥234.00 | 2 | 4 | 0 | ¥0.00 | 0 | ¥0.00 |  | https://www.digikey.jp/short/rdhw9z22
DF51A-6DP-2DSA | J14 |  | DF51A-6DP-2DSA | DigiKey | H125869-ND | ¥67.00 | 1 | 999 | 0 | ¥0.00 | 0 | ¥0.00 |  | https://www.digikey.jp/short/923d0jnh
DF51A-8DP-2DS(20) |  | J11 | DF51A-8DP-2DS(20) | DigiKey | 26-DF51A-8DP-2DS(20)-ND | ¥217.00 | 1 | 0 | 1 | ¥217.00 | 2 | ¥434.00 |  | https://www.digikey.jp/short/9mwdm723
DFPlayer mini (MP3プレーヤー) | U6 |  | DFR0299 | 秋月電子通商 | M-12544 | ¥1050.00 | 1 | 2 | 0 | ¥0.00 | 0 | ¥0.00 |  | https://akizukidenshi.com/catalog/g/gM-12544/
I2C シリアルEEPROM 24LC256(マイクロチップ) | U7 |  | 24LC256 | 秋月電子通商 | I-00705 | ¥100.00 | 1 | 1 | 0 | ¥0.00 | 0 | ¥0.00 |  | https://akizukidenshi.com/catalog/g/gI-00705/
INA219BIDCNT | U4, U5 | U4, U5 | INA219BIDCNT | チップワンストップ | C1S746202027091 | ¥714.00 | 4 | 0 | 4 | ¥2856.00 | 8 | ¥5712.00 |  | https://www.chip1stop.com/view/dispDetail/DispDetail?partId=TI01-0202709
MCR03EZPFX1001 | R4, R8-R10, R23, R27, R29, R31-R33, R35, R37-R39, R41-R47, R50-R52, R54-R57, R59-R67 | R4, R9, R10, R23, R29, R32, R35, R37-R39, R41-R47, R50, R51, R59-R67 | MCR03EZPFX1001 | チップワンストップ | C1S625900210977 | ¥2.14 | 68 | 999 | 0 | ¥0.00 | 0 | ¥0.00 |  | https://www.chip1stop.com/view/dispDetail/DispDetail?partId=ROHM-0021097
チップ抵抗 1/10W1kΩ (5000個入) | R1, R6, R7, R14-R17, R21, R22, R25 | R1, R6, R7, R14-R17, R21, R22, R25, R27, R33, R52, R56, R69, R73, R77, R81, R85, R88 | RC0603J1K | 秋月電子通商 | R-14122 | ¥980.00 | 30 | 21 | 1 | ¥980.00 | 1 | ¥980.00 |  | https://akizukidenshi.com/catalog/g/gR-14122/
MCR03EZPFX1004 | R5 | R5 | MCR03EZPFX1004 | チップワンストップ | C1S625900001999 | ¥2.13 | 11 | 999 | 0 | ¥0.00 | 0 | ¥0.00 |  | https://www.chip1stop.com/view/dispDetail/DispDetail?partId=ROHM-0000199
MCR03EZPFX1200 | R26 | R26, R24, R31, R49, R55, R68, R72, R76, R80, R84 | MCR03EZPFX1200 | チップワンストップ | C1S625900401162 | ¥1.68 | 2 | 999 | 0 | ¥0.00 | 0 | ¥0.00 |  | https://www.chip1stop.com/view/dispDetail/DispDetail?partId=ROHM-0040116
MCR03EZPFX1202 |  | R48, R53, R57, R70, R74, R78, R82, R86 | MCR03EZPFX1202 | チップワンストップ | C1S625900609278 | ¥1.44 | 8 | 999 | 0 | ¥0.00 | 0 | ¥0.00 |  | https://www.chip1stop.com/view/dispDetail/DispDetail?partId=ROHM-0060927
MCR03EZPFX2001 |  | R40, R54, R58, R71, R75, R79, R83, R87 | MCR03EZPFX2001 | チップワンストップ | C1S625900209546 | ¥1.98 | 8 | 999 | 0 | ¥0.00 | 0 | ¥0.00 |  | https://www.chip1stop.com/view/dispDetail/DispDetail?partId=ROHM-0020954
MCR03EZPFX2201 | R34, R36 | R34, R36 | MCR03EZPFX2201 | チップワンストップ | C1S625900401311 | ¥2.01 | 4 | 999 | 0 | ¥0.00 | 0 | ¥0.00 |  | https://www.chip1stop.com/view/dispDetail/DispDetail?partId=ROHM-0040131
MCR03EZPFX22R0 | R2, R3 | R2, R3 | MCR03EZPFX22R0 | チップワンストップ | C1S625900419453 | ¥2.05 | 3 | 999 | 0 | ¥0.00 | 0 | ¥0.00 |  | https://www.chip1stop.com/view/dispDetail/DispDetail?partId=ROHM-0041945
MCR03EZPFX2400 |  | R8 | MCR03EZPFX2400 | チップワンストップ | C1S625900394808 | ¥2.17 | 1 | 999 | 0 | ¥0.00 | 0 | ¥0.00 |  | https://www.chip1stop.com/view/dispDetail/DispDetail?partId=ROHM-0039480
MCR03EZPFX2401 | R30 | R30 | MCR03EZPFX2401 | チップワンストップ | C1S625900401357 | ¥1.51 | 2 | 999 | 0 | ¥0.00 | 0 | ¥0.00 |  | https://www.chip1stop.com/view/dispDetail/DispDetail?partId=ROHM-0040135
MCR03EZPFX3000 |  | R19, R20 | MCR03EZPFX3000 | チップワンストップ | C1S625900401427 | ¥2.01 | 2 | 999 | 0 | ¥0.00 | 0 | ¥0.00 |  | https://www.chip1stop.com/view/dispDetail/DispDetail?partId=ROHM-0040142
MCR03EZPFX3301 | R12 | R12 | MCR03EZPFX3301 | チップワンストップ | C1S625900394817 | ¥2.04 | 2 | 999 | 0 | ¥0.00 | 0 | ¥0.00 |  | https://www.chip1stop.com/view/dispDetail/DispDetail?partId=ROHM-0039481
MCR03EZPFX3601 | R28 | R28 | MCR03EZPFX3601 | チップワンストップ | C1S625900401506 | ¥0.90 | 2 | 999 | 0 | ¥0.00 | 0 | ¥0.00 |  | https://www.chip1stop.com/view/dispDetail/DispDetail?partId=ROHM-0040150
MCR03EZPFX5601 | R11 | R11 | MCR03EZPFX5601 | チップワンストップ | C1S625900401685 | ¥1.88 | 2 | 999 | 0 | ¥0.00 | 0 | ¥0.00 |  | https://www.chip1stop.com/view/dispDetail/DispDetail?partId=ROHM-0040168
NchパワーMOSFET 30V5.7A AO3400A (10個入) |  | Q4-12 | AO3400A | 秋月電子通商 | I-14653 | ¥220.00 | 9 | 8 | 1 | ¥220.00 | 1 | ¥220.00 |  | https://akizukidenshi.com/catalog/g/gI-14653/
NTCサーミスタ(温度検知・温度補償用)10kΩ 1608 (20個入) | TH1 | TH1 | NCP18XH103F03RB | 秋月電子通商 | P-05252 | ¥200.00 | 2 | 11 | 0 | ¥0.00 | 0 | ¥0.00 |  | https://akizukidenshi.com/catalog/g/gP-05252/
PchパワーMOSFET 60V8A TJ8S06M3L | Q1, Q2 | Q1, Q2 | TJ8S06M3L(T6L1NQ) | 秋月電子通商 | I-13964 | ¥60.00 | 4 | 0 | 4 | ¥240.00 | 8 | ¥480.00 |  | https://akizukidenshi.com/catalog/g/gI-13964/
RS485/RS422トランシーバ LTC485CN8#PBF | U8 | U8 | LTC485CN8#PBF | 秋月電子通商 | I-02792 | ¥250.00 | 2 | 0 | 2 | ¥500.00 | 4 | ¥1000.00 |  | https://akizukidenshi.com/catalog/g/gI-02792/
TVSダイオード(サージ吸収素子) SMAJ45A (20個入) | D2, D3 | D2, D3 | SMAJ45A | 秋月電子通商 | I-07409 | ¥120.00 | 4 | 14 | 0 | ¥0.00 | 0 | ¥0.00 | D | https://akizukidenshi.com/catalog/g/gI-07409/
USBシリアル変換IC FT232RL | U1 | U1 | FT232RL | 秋月電子通商 | I-01739 | ¥550.00 | 2 | 0 | 2 | ¥1100.00 | 4 | ¥2200.00 |  | https://akizukidenshi.com/catalog/g/gI-01739/
WSL2816R1000FEH | R13, R18 | R13, R18 | WSL2816R1000FEH | チップワンストップ | C1S803606529401 | ¥79.50 | 4 | 0 | 4 | ¥318.00 | 8 | ¥636.00 |  | https://www.chip1stop.com/view/dispDetail/DispDetail?partId=VISH-0652940
Wurth Elektronik Micro USBコネクタ | J3 | J3 | 629105150521 | モノタロウ | 41398097 | ¥319.00 | 2 | 0 | 2 | ¥638.00 | 4 | ¥1276.00 |  | https://www.monotaro.com/p/4139/8097/
オレンジ色チップLED [1608] OSOR1608C1A (20個入) | D7-D9, D19-D30 | D7-D9, D19, D22-D30 | OSOR1608C1A | 秋月電子通商 | I-06416 | ¥200.00 | 28 | 25 | 1 | ¥200.00 | 2 | ¥400.00 | D | https://akizukidenshi.com/catalog/g/gI-06416/
クリスタル(水晶発振子) 16MHz | Y1 | Y1 | HUSG-16.000-20 | 秋月電子通商 | P-08671 | ¥30.00 | 2 | 2 | 0 | ¥0.00 | 2 | ¥60.00 |  | https://akizukidenshi.com/catalog/g/gP-08671/
ターミナルブロック 2.54mm 2P 緑 縦 | J10, J12 |  | TB401-1-2-E | 秋月電子通商 | P-01404 | ¥40.00 | 2 | 3 | 0 | ¥0.00 | 1 | ¥40.00 |  | https://akizukidenshi.com/catalog/g/gP-01404/
ターミナルブロック 2.54mm 4P 緑 縦 | J2, J15 | J2, J9, J10, J15 | TB401-1-4-E | 秋月電子通商 | P-07756 | ¥80.00 | 6 | 4 | 2 | ¥160.00 | 8 | ¥640.00 |  | https://akizukidenshi.com/catalog/g/gP-07756/
ターミナルブロック 2P 緑 縦 | J4-6 | J4-6, J12 | TB411-2-2-E-1 | 秋月電子通商 | P-06309 | ¥50.00 | 7 | 1 | 6 | ¥300.00 | 13 | ¥650.00 |  | https://akizukidenshi.com/catalog/g/gP-06309/
チェック端子(テストポイント) TEST-8 | TP1-4 | TP1-4 | TEST-8 | 秋月電子通商 | P-12215 | ¥20.00 | 8 | 8 | 8 | ¥160.00 | 8 | ¥160.00 |  | https://akizukidenshi.com/catalog/g/gP-12215/
チップインダクター 10μH1.7A(5個入) | L1 | L1 | DFE322512F-100M | 秋月電子通商 | P-14977 | ¥220.00 | 2 | 2 | 0 | ¥0.00 | 1 | ¥220.00 |  | https://akizukidenshi.com/catalog/g/gP-14977/
チップダイオード 1000V1A GS1010FL (10個入) | D1, D4, D18 | D1, D4 | GS1010FL | 秋月電子通商 | I-06014 | ¥100.00 | 5 | 23 | 0 | ¥0.00 | 0 | ¥0.00 |  | https://akizukidenshi.com/catalog/g/gI-06014/
チップトランジスタ 2SC3325-Y 50V500mA (20個入) | Q3 | Q3 | 2SC3325-Y | 秋月電子通商 | I-00628 | ¥100.00 | 2 | 15 | 0 | ¥0.00 | 0 | ¥0.00 |  | https://akizukidenshi.com/catalog/g/gI-00628/
チップ積層セラミックコンデンサー 0.1μF50V X8L 1608 (40個入) | C1-C3, C5-C8, C11-C13, C15, C17, C18 | C1-C8, C11-C13, C15, C17, C18 | GRM188R6YA106MA73 | 秋月電子通商 | P-16143 | ¥110.00 | 27 | 19 | 1 | ¥110.00 | 2 | ¥220.00 |  | https://akizukidenshi.com/catalog/g/gP-16143/
チップ積層セラミックコンデンサー 10μF50V B 3216 (10個入) | C14, C16 | C14, C16 | GRM31CB31H106KA12 | 秋月電子通商 | P-17338 | ¥250.00 | 4 | 0 | 1 | ¥250.00 | 1 | ¥250.00 |  | https://akizukidenshi.com/catalog/g/gP-17338/
チップ積層セラミックコンデンサー 15pF50V NP0 1608 (40個入) | C9, C10 | C9, C10 | CC0603N150J500 | 秋月電子通商 | P-13312 | ¥100.00 | 4 | 70 | 0 | ¥0.00 | 0 | ¥0.00 |  | https://akizukidenshi.com/catalog/g/gP-13312/
ピンソケット(メス) 1×6(6P) | J1 | J1 | FH-1x6SG/RH | 秋月電子通商 | C-03784 | ¥20.00 | 2 | 0 | 2 | ¥40.00 | 4 | ¥80.00 |  | https://akizukidenshi.com/catalog/g/gC-03784/
ピンヘッダ 1×2 (2P) (10個入) | SW11-SW16, SW18-SW25 | SW11, SW18-SW25 | PH-1X2SG | 秋月電子通商 | C-08593 | ¥25.00 | 23 | 13 | 2 | ¥50.00 | 4 | ¥100.00 |  | https://akizukidenshi.com/catalog/g/gC-08593/
フォトカプラ TLP785(GBランク) |  | U6, U7 | TLP785(GB F) | 秋月電子通商 | I-07554 | ¥20.00 | 2 | 2 | 0 | ¥0.00 | 2 | ¥40.00 |  | https://akizukidenshi.com/catalog/g/gI-07554/
リセッタブルヒューズ 0.5A トリップ電流:1A 耐圧:13.2V (4個入) | F1 | F1 | MF-NSMF050-2 | 秋月電子通商 | P-15300 | ¥100.00 | 2 | 1 | 1 | ¥100.00 | 1 | ¥100.00 |  | https://akizukidenshi.com/catalog/g/gP-15300/
三端子レギュレーター 5V1.5A TO-252 NJM7805SDL1 | U3 | U3 | NJM7805SDL1 | 秋月電子通商 | I-11237 | ¥50.00 | 2 | 0 | 2 | ¥100.00 | 4 | ¥200.00 |  | https://akizukidenshi.com/catalog/g/gI-11237/
青色チップLED [1608] OSBL1608 (20個入) | D12, D14 | D12, D14 | OSBL1608C1A | 秋月電子通商 | I-03982 | ¥200.00 | 4 | 43 | 0 | ¥0.00 | 0 | ¥0.00 |  | https://akizukidenshi.com/catalog/g/gI-03982/
赤色チップLED [1608] 625nm 120度 OSHR1608 (20個入) | D16, D17 | D16, D17 | OSHR1608C1A | 秋月電子通商 | I-03978 | ¥200.00 | 4 | 12 | 0 | ¥0.00 | 0 | ¥0.00 |  | https://akizukidenshi.com/catalog/g/gI-03978/
表面実装用ショットキーバリアダイオード 40V2A SS2040FL (20個入) | D5, D6 | D5, D6 | SS2040FL | 秋月電子通商 | I-02073 | ¥300.00 | 4 | 14 | 0 | ¥0.00 | 0 | ¥0.00 |  | https://akizukidenshi.com/catalog/g/gI-02073/
表面実装用タクトスイッチ TVAF06-A020B-R (5個入) | SW1, SW2, SW17 | SW1, SW2, SW17 | TVAF06-A020B-R | 秋月電子通商 | P-14888 | ¥110.00 | 6 | 0 | 6 | ¥660.00 | 12 | ¥1320.00 |  | https://akizukidenshi.com/catalog/g/gP-14888/
緑色チップLED [1608] OSTG1608C1A (20個入) | D10, D11 | D10, D11 | OSTG1608C1A | 秋月電子通商 | I-06417 | ¥250.00 | 4 | 10 | 0 | ¥0.00 | 0 | ¥0.00 |  | https://akizukidenshi.com/catalog/g/gI-06417/
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

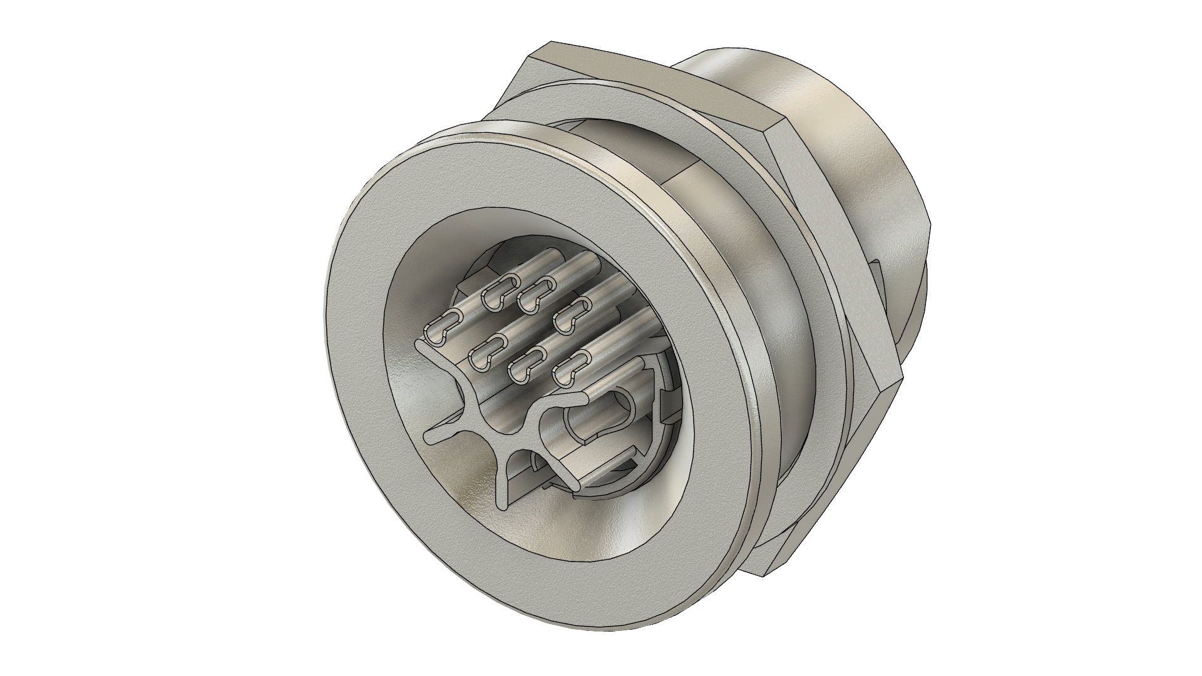
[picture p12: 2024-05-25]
Documents/Pictures/Parts/LF13WBRB-11P v2.png

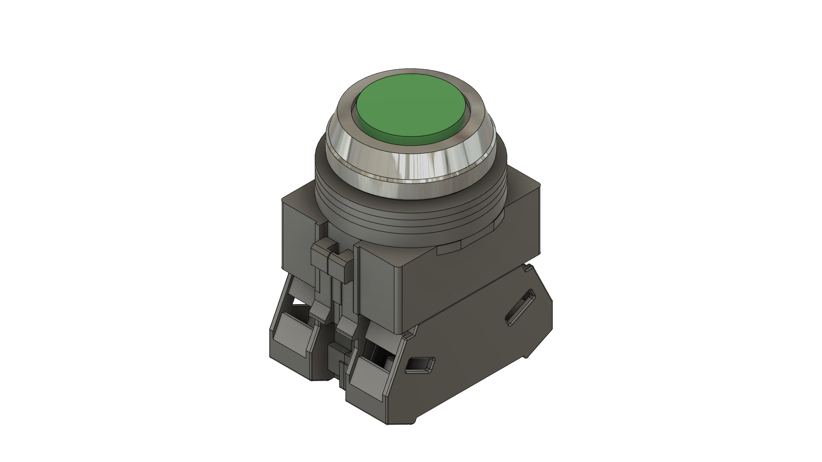
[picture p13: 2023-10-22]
Documents/Pictures/Parts/AOS1N v2.png

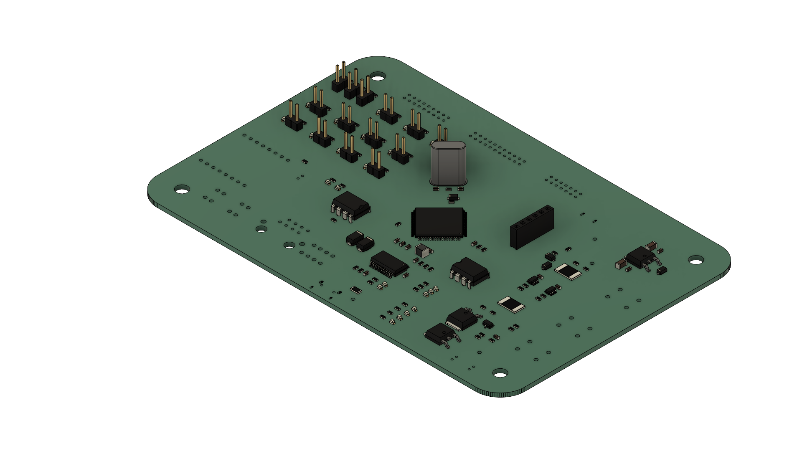
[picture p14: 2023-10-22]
Documents/Pictures/Parts/LaunchController v1.png

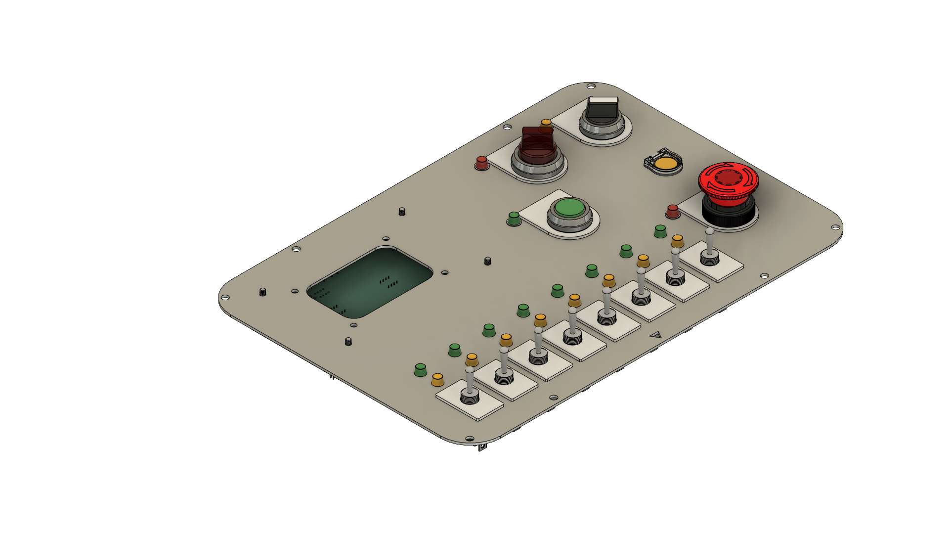
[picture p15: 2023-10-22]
Documents/Pictures/Parts/BreadBoardModel_NK915_HOME.png

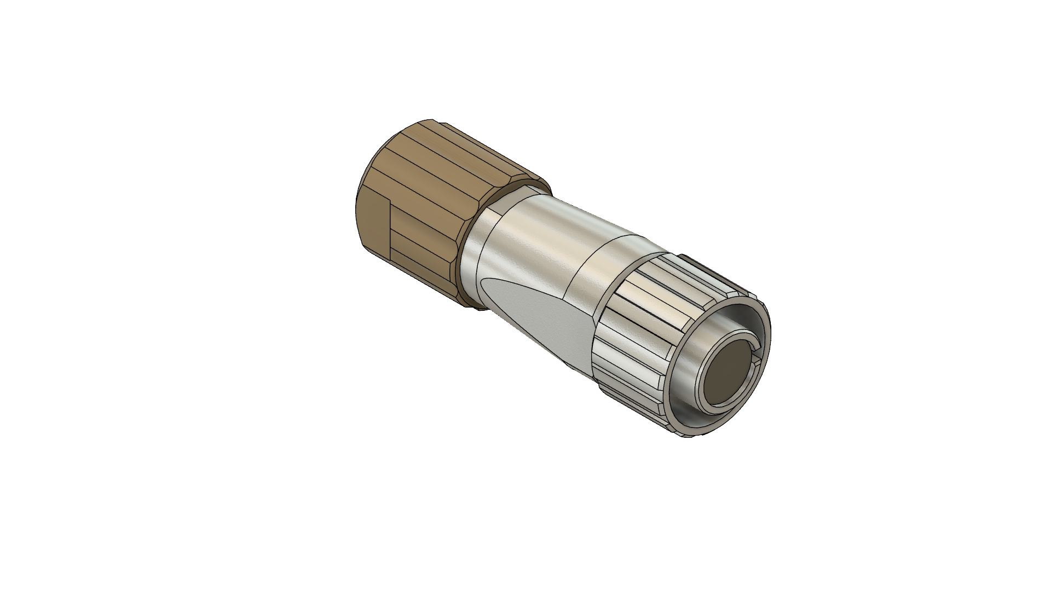
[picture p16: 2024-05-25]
Documents/Pictures/Parts/LF07WBP-3S.png

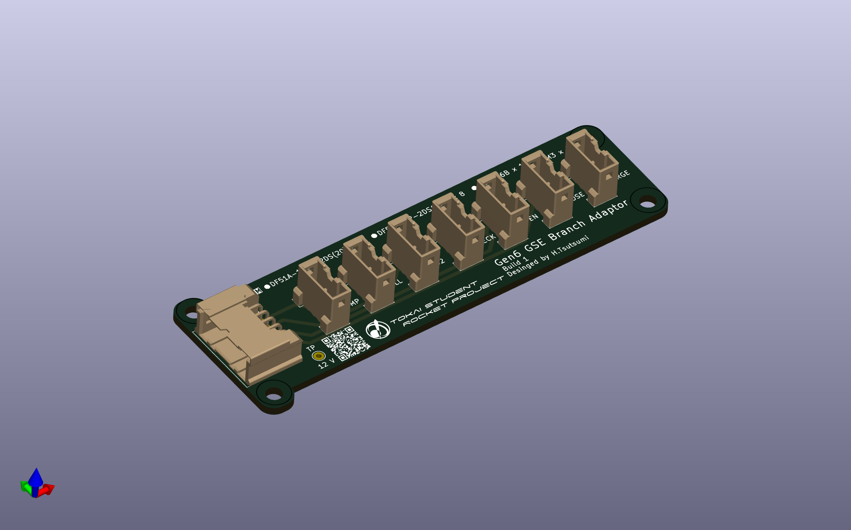
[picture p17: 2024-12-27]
Documents/Pictures/Parts/BranchAdaptor2.png

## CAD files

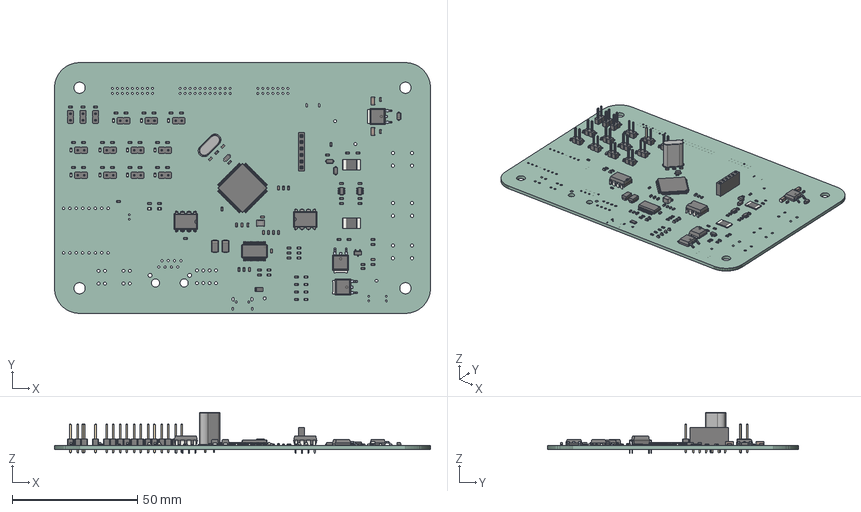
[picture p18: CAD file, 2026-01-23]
KiCad/LaunchController/LaunchController.step
150.0 x 100.0 x 16.4 mm
PCB

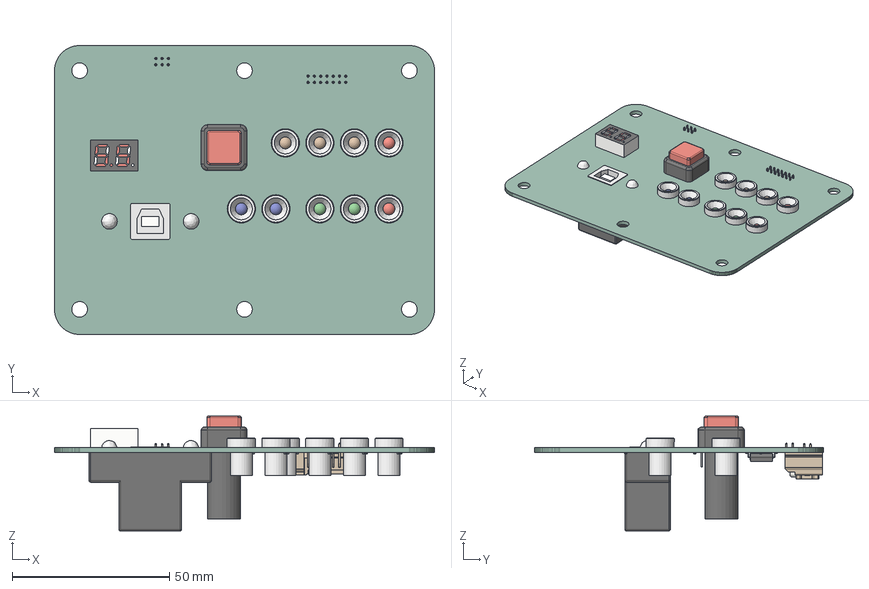
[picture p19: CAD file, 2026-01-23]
KiCad/StatusPanel/StatusPanel.step
121.0 x 92.0 x 36.6 mm
PCB

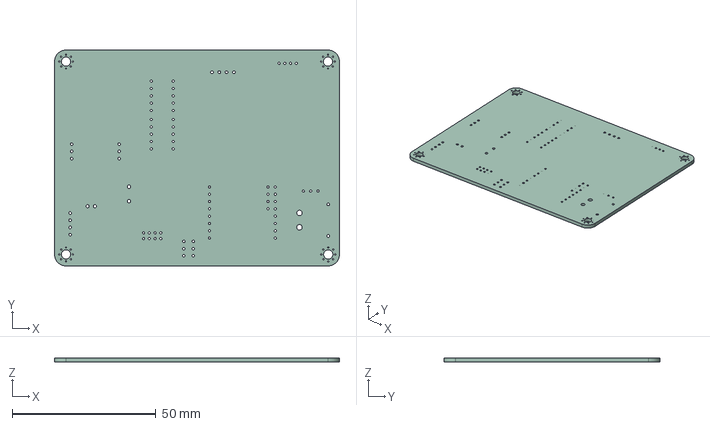
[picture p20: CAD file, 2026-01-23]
KiCad/THRValveControlModule/THRValveControlModule.step
99.0 x 75.0 x 1.51 mm

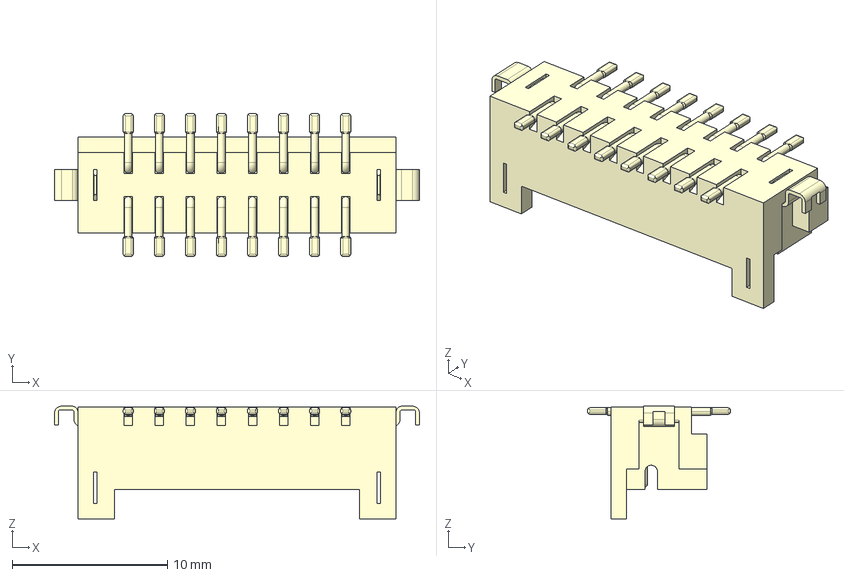
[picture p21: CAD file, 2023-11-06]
KiCad/StatusPanel/DF11C-16DP-2V.stp
23.5 x 9.20 x 7.25 mm

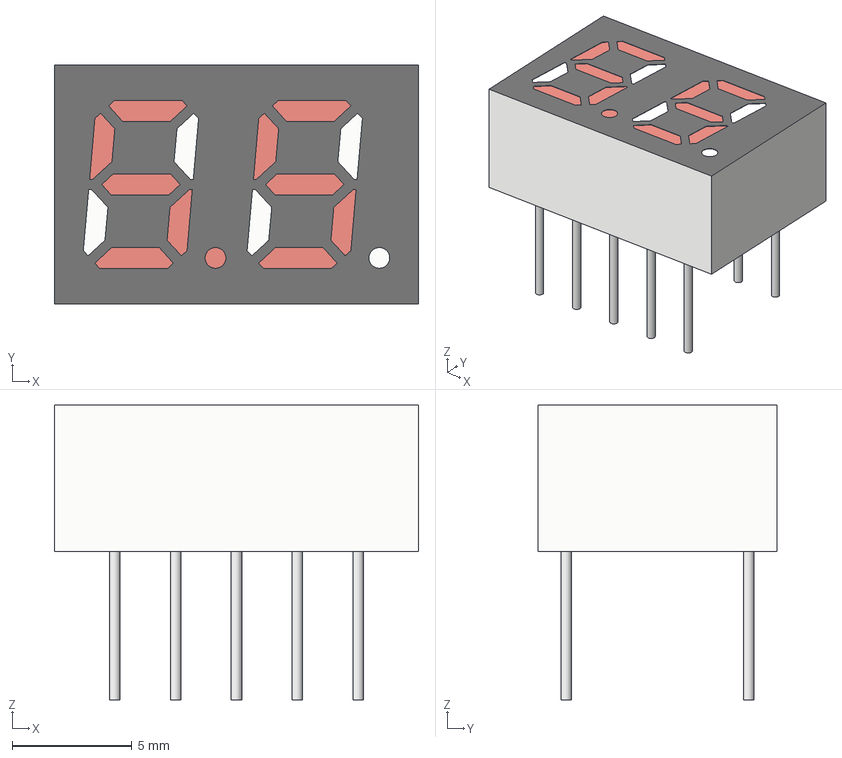
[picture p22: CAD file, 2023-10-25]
KiCad/StatusPanel/7SEG.step
15.2 x 10.0 x 12.3 mm

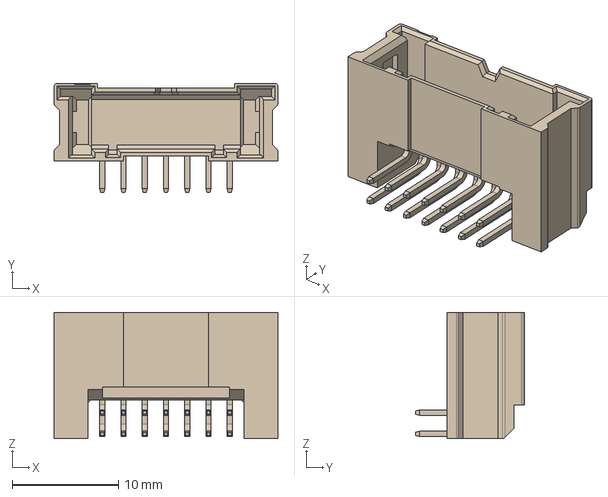
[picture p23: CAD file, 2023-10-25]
KiCad/StatusPanel/WNCW-1800092.stp
21.1 x 10.3 x 11.9 mm

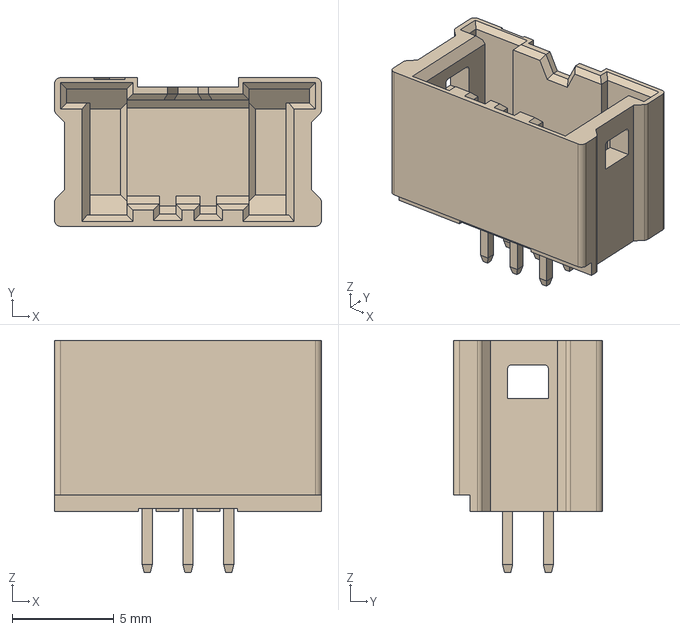
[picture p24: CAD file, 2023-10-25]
KiCad/StatusPanel/DF51A-6DP-2DSA.stp
13.1 x 7.30 x 11.4 mm

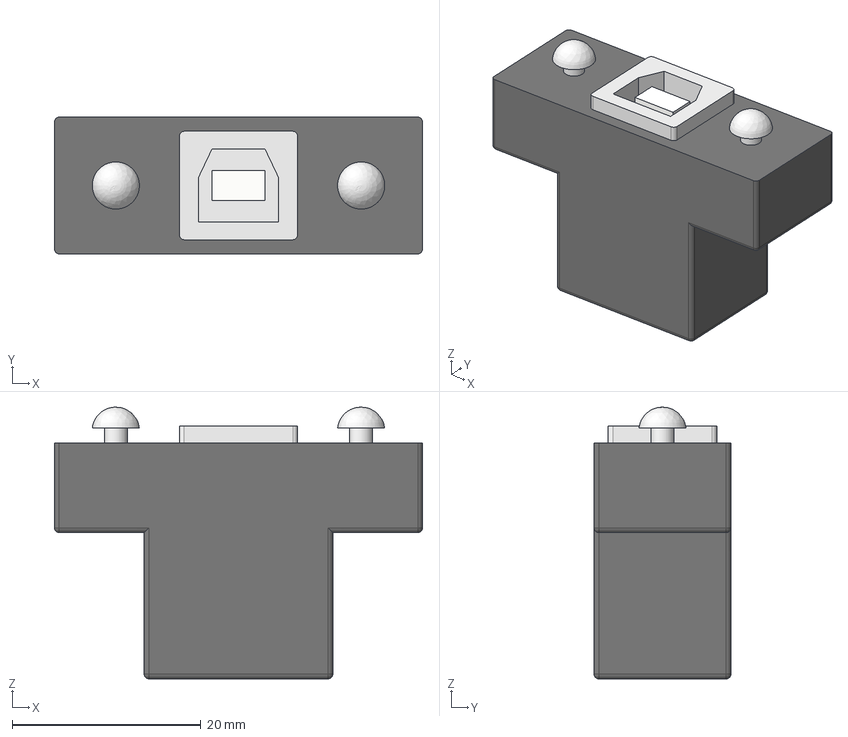
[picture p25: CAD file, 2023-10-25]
KiCad/StatusPanel/USB.step
39.0 x 14.5 x 28.8 mm

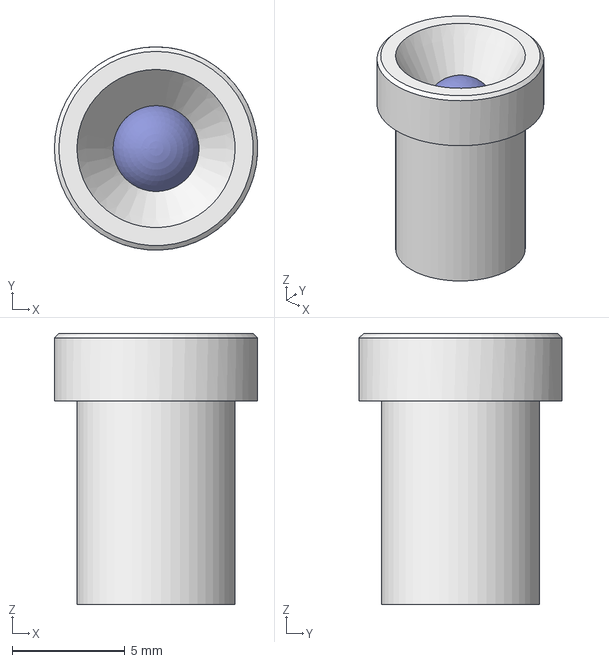
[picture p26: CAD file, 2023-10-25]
KiCad/StatusPanel/LED_Bracket_Blue.step
9.00 x 9.00 x 12.0 mm

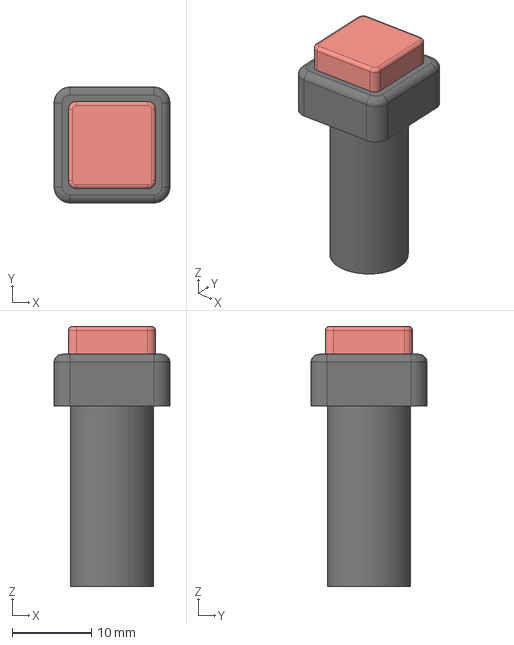
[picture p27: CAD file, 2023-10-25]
KiCad/StatusPanel/Button.step
14.6 x 14.6 x 32.8 mm

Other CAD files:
KiCad/StatusPanel/LED_Bracket_Orange.step
KiCad/StatusPanel/LED_Bracket_Red.step
KiCad/StatusPanel/LED_Bracket_Green.step

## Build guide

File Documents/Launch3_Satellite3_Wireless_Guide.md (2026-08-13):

# Launch3.0 & Satellite3.0 無線通信遠隔制御システム仕様ガイド

このドキュメントでは，Gen6 GSE システムにおける **Launch3.0** および **Satellite3.0** の新環境構成と，**Raspberry Pi 4 を用いた無線通信遠隔制御アルゴリズム**およびフェールセーフ仕様を解説します．

---

## 1. システム概要とハードウェア構成

Launch3.0 / Satellite3.0 は，従来の RS485 有線通信システム（Serial1）をそのまま全維持しつつ，新たに **Raspberry Pi 4 からの無線通信を用いた遠隔制御・テレメトリ監視** に対応させた最新世代の環境です．

### マイコン通信ポート割り当て (ATmega2560)
| シリアルポート | ボーレート | 接続先・用途 |
|---|---|---|
| **`Serial` (更新)** | **115200 bps** | **USB (FT232RL) - Raspberry Pi 4 無線通信 / 遠隔制御インターフェース**（※従来の Python GUI 機能は無効化） |
| `Serial1` | 115200 bps | RS485 (LTC485) - サテライト・ノード間有線通信 |
| `Serial2` | 9600 bps | DFPlayer Mini - 音声アナウンス再生 |

---

## 2. 無線通信パケット仕様 (`MsgPacketizer`)

Raspberry Pi 4 とのパケット送信には `MsgPacketizer` ライブラリを使用します．

### パケット ID 定義 (Launch3.0)

| パケット ID | Hex / Dec | パケット名 | 送信方向 | 説明 / ペイロード |
|---|---|---|---|---|
| `0x20` | 32 | `RASPI_COMMAND` | RasPi → Launch3 | 遠隔制御コマンド (`uint8_t cmdType`, `uint8_t param`) |
| `0x21` | 33 | `RASPI_HEARTBEAT_L_TO_R` | Launch3 → RasPi | 生存確認（ハートビート送信） |
| `0x22` | 34 | `RASPI_HEARTBEAT_R_TO_L` | RasPi → Launch3 | 生存確認（ハートビート受信） |
| `0x23` | 35 | `RASPI_TELEMETRY` | Launch3 → RasPi | テレメトリ一括送信 (`cmd_state`, `fb_state`, `sequence_flag`, `pressure_MPa`, `limitSwitchState`) |
| `0x24` | 36 | `RASPI_WIRELESS_STATUS` | Launch3 → RasPi | 無線リンクステータス同期 (`uint8_t status`) |

### コマンド種別 (`cmdType`)

| 値 | コマンド名 | 説明 |
|---|---|---|
| `1` | `EMERGENCY_STOP` | 遠隔緊急停止トリガー |
| `2` | `PEACEFUL_STOP` | 遠隔通常停止トリガー |
| `3` | `FILL_START` | 遠隔充填シーケンス開始（セーフティ解除必須） |
| `4` | `IGNITION_START` | 遠隔点火シーケンス開始（セーフティ解除必須） |
| `5` | `ARM_SAFETY` | 遠隔セーフティ状態設定 (`param: 1=ARMED, 0=DISARMED`) |
| `6` | `VALVE_CONTROL` | 遠隔手動弁制御 (`param`: 各弁ビットマップ) |
| `7` | `ZERO_CALIB` | 遠隔ゼロ点校正要求 |

---

## 3. 無線化必須条件アルゴリズム (Wireless Interlock & Fail-Safe)

本環境では，「**無線通信が正常に接続・維持されていること**」をアルゴリズム実行の**必須条件**として実装しています．

### 1. 生存監視タスク (`checkWirelessTask`)
- **実行頻度**: 2Hz (0.5秒おき)
- **タイムアウト時間**: 3.0秒 (3000 ms)
- 3.0秒以上 Raspberry Pi 4 からのハートビートパケット（またはコマンド）の受信がない場合，`isWirelessConnected = false` と判定します．

### 2. 遠隔コマンド受付インターロック
- `isWirelessConnected == false` の場合，受信したあらゆる遠隔動作コマンド（弁開閉，シーケンス開始）を直ちに**拒否（REJECT）**し，エラーランプ（ERR LED）を点灯させます．

### 3. 無線断絶時のフェールセーフ（自動緊急停止）
- 自動充填シーケンス（`fillSequenceIsActive`）または自動点火シーケンス（`ignitionSequenceIsActive`）の実行中に無線リンクが途絶した場合：
  - ただちに `sequence::emergencyStop()` が自動発動します．
  - 各種バルブは直ちに安全状態（FILL閉，O2閉，点火OFF，CLOSE発動，パージON）へと遷移し，事故を未然に防止します．

---

## 4. PlatformIO でのビルドと書き込み方法

### Launch3.0 のビルド
```bash
pio run -e Launch3
```

### Satellite3.0 のビルド
```bash
pio run -e Satellite3
```

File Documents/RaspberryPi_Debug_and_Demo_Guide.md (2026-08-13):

# Raspberry Pi 4 デモモード＆ターミナルデバッグガイド

本ドキュメントでは，実機マイコン（Launch3.0 / Satellite3.0）が手元にない環境でも，Raspberry Pi 4（または開発用 PC）単体で**デモモード（シミュレータ）およびコマンドプロンプト（CLI）を用いたデバッグ手順**について解説します．

---

## 1. 概要とデモモードの仕組み

`raspi_gse_control.py` には，実機マイコンが接続されていない状態でも動作確認ができる **デモシミュレータ（--demo）** および **ターミナル直接操作 shell (--cli)** が組み込まれています．

- **デモモード (`--demo`)**:
  - 実機のシリアル接続 (`/dev/ttyUSB0`) を必要としません．
  - 圧力センサー数値（0.00 ～ 4.50 MPa）の充填・排出ダイナミクスを内部スレッドで擬似計算します．
  - 各電磁弁の指示（CMD）とフィードバック（FB）を自動追従・シミュレートします．
  - バックグラウンドで Web ダッシュボード (Port 5000) も同時に動作するため，ブラウザと CLI の両方からデバッグ可能です．

---

## 2. 起動方法

### 2.1 デモモード (実機不要・Web+CLI デバッグ)
ターミナルで以下のコマンドを実行します：

```bash
python3 tools/raspi_gse_control/raspi_gse_control.py --demo
```

### 2.2 実機接続時の CLI デバッグモード
実機マイコンが接続されている状態で CLI プロンプトを起動する場合：

```bash
python3 tools/raspi_gse_control/raspi_gse_control.py --port /dev/ttyUSB0
```

---

## 3. ターミナル CLI コマンド一覧

起動すると，ターミナル上に `GSE-Debug>` プロンプトが表示され，キーボードから直接制御コマンドを入力できます．

| コマンド | 引数例 | 説明 |
|---|---|---|
| `status` | - | 現在の圧力，セーフティ，リミットスイッチ，全バルブ状態を一覧表示 |
| `arm` | `on` / `off` | セーフティ装置を ARM (解除) / DISARM (施錠) |
| `fill` | - | 遠隔充填シーケンス開始 (圧力上昇シミュレーション開始) |
| `ignite` | - | 遠隔点火シーケンス開始 (O2, IGNITER, OPEN 作動) |
| `estop` | - | 🚨 **緊急停止 (EMERGENCY STOP)** (即座に DUMP, PURGE 開) |
| `peace` | - | ⏹️ 通常停止 (PEACEFUL STOP) |
| `valve` | `FILL 1` / `DUMP 0` | 指定電磁弁の手動トグル (`SHIFT`, `FILL`, `DUMP`, `OXYGEN`, `IGNITER`, `OPEN`, `CLOSE`, `PURGE`) |
| `limit` | `1` / `0` | リミットスイッチ ch5 の押下 / 解放シミュレーション |
| `zero` | - | ゼロ点校正リクエスト送信 |
| `help` | - | コマンドヘルプを表示 |
| `quit` | - | デバッグサーバーを終了 |

---

## 4. デバッグ実行例 (Walkthrough Example)

### ステップ 1: ステータスの確認
```text
GSE-Debug> status

------------------- [ GSE CURRENT STATUS ] -------------------
  Mode           : [DEMO MOCK MODE]
  Wireless Link  : ● OK (CONNECTED)
  Safety Armed   : 🔒 DISARMED (施錠中)
  N2O Pressure   : 0.000 MPa
  Limit Switch 5 : CLOSED (SAFE)
  Sequence State : Fill=False, Ignite=False, E-Stop=False
  Valves State   :
    - SHIFT    : CMD=OFF | FB=OFF
    - FILL     : CMD=OFF | FB=OFF
    - DUMP     : CMD=OFF | FB=OFF
    - OXYGEN   : CMD=OFF | FB=OFF
    - IGNITER  : CMD=OFF | FB=OFF
    - OPEN     : CMD=OFF | FB=OFF
    - CLOSE    : CMD=OFF | FB=OFF
    - PURGE    : CMD=OFF | FB=OFF
--------------------------------------------------------------
```

### ステップ 2: セーフティの解除 (ARM)
```text
GSE-Debug> arm on
[SIMULATOR] 🛡️ SAFETY ARM SET TO: ARMED
```

### ステップ 3: 充填シーケンスの開始
```text
GSE-Debug> fill
[SIMULATOR] ⛽ FILL SEQUENCE STARTED!
```
`status` を入力すると，N2O 圧力が 0.000 MPa から 4.500 MPa へ向けて徐々に上昇するアニメーションシミュレーションを確認できます．

### ステップ 4: 緊急停止 (EMERGENCY STOP) テスト
```text
GSE-Debug> estop
[SIMULATOR] 🚨 EMERGENCY STOP TRIGGERED!
```
緊急停止により `DUMP`, `PURGE`, `CLOSE` が即座に ON になり，圧力が 0.000 MPa へ降下することを確認できます．

---

## 5. Web ダッシュボードとの同時デバッグ

デモモード起動中，ブラウザで `http://localhost:5000` （Raspberry Pi の場合は `http://<IP>:5000`）にアクセスすると，ターミナルでのコマンド入力結果がリアルタイムでブラウザ画面上のメーターおよびバルブ LED に反映されます．

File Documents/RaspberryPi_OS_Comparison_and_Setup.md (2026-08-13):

# Raspberry Pi 4 OS 選定比較と GSE 無線遠隔制御システム構築ガイド

本ドキュメントでは，Gen6 GSE システム（Launch3.0 / Satellite3.0）の無線中継・遠隔制御ノードとして使用する **Raspberry Pi 4 の OS 選定の比較検討** および **セットアップ・運用手順** について解説します．

---

## 1. Raspberry Pi 4 OS 比較検討 (Evaluation & OS Selection)

ロケット実験場（Ground Support Equipment: GSE）における無線通信・遠隔制御用途として，代表的な 4 種類の OS を比較評価しました．

| OS 名 | カーネル / ベース | メモリ/CPU負荷 | シリアル/通信安定性 | 開発・構築容易性 | 総合評価 |
|---|---|---|---|---|---|
| **Raspberry Pi OS (64-bit) Lite** | Debian Bookworm | **極めて軽量** (<150MB RAM) | **最高 (公式最適化)** | **容易 (Python/pySerial完備)** | **◎ 推奨 (最優先)** |
| **Raspberry Pi OS (64-bit) Desktop** | Debian Bookworm | 軽量 (~400MB RAM) | 最高 (公式最適化) | 容易 (GUI操作可能) | ○ 推奨 (現地画面表示用) |
| **Ubuntu Server 24.04 LTS (64-bit)** | Canonical Ubuntu | 中程度 (~350MB RAM) | 良好 | 普通 (ROS2連携時に有利) | △ 条件付き推奨 |
| **Alpine Linux (64-bit)** | Alpine / musl | 極小 (<50MB RAM) | 良好 | 困難 (musl/パッケージ制約) | × 非推薦 |
| **Raspberry Pi OS + PREEMPT_RT** | RT-Patch Linux | 低 | 高精度 (低ジッター) | 難 (カーネル自作ビルド) | △ リアルタイム特化時 |

### 選定理由と結論

1. **推奨 OS: `Raspberry Pi OS (64-bit) Lite` (Headless 運用時) または `Desktop`**
   - **理由 1 (安定性と堅牢性)**: 公式の Broadcom SoC ドライバおよび UART/USB シリアルドライバが最も最適化されており，長時間のシリアル通信および Wi-Fi AP / クライアント動作においてドロップアウトが発生しにくい．
   - **理由 2 (自動アップデート事故の防止)**: Ubuntu などで問題となるバックグラウンドでの無告自動アップデート (`unattended-upgrades` や `snapd`) による CPU/ディスク負荷のスパイクが未然に防止でき，打ち上げ実験中の通信遅延を防ぐことができる．
   - **理由 3 (エコシステム)**: Python 3, `pySerial`, `msgpack`, `Flask` などの必須ライブラリが標準でスムーズに動作し，メンテナンスが容易．

> [!TIP]
> **推奨構成**: ディスプレイを接続せず Wi-Fi / Ethernet 経由でブラウザ・スマホ等から遠隔操作する場合は **Raspberry Pi OS Lite (64-bit)** を使用してください．現地現場で直接 HDMI モニタを接続して操作する場合は **Raspberry Pi OS Desktop (64-bit)** を選定します．

---

## 2. Raspberry Pi 4 の初期セットアップ手順

### Step 1: SDカードへの OS 書き込み
1. PC に **Raspberry Pi Imager** をインストールします．
2. OS に **Raspberry Pi OS (64-bit)** (Lite または Desktop) を選択します．
3. 設定（OS customization）で以下を有効化します：
   - ホスト名: `raspi-gse`
   - ユーザー名 / パスワードの設定
   - Wi-Fi 設定（実験場のアクセスポイント SSID とパスワード）
   - **SSH を有効化**

### Step 2: 依存ライブラリのインストール
Raspberry Pi 4 に SSH または ターミナルでログインし，以下のコマンドを実行します：

```bash
sudo apt update && sudo apt upgrade -y
sudo apt install -y python3-pip python3-serial python3-msgpack python3-flask
```

---

## 3. 電源投入後の操作手順 (Post Boot Step-by-Step Guide)

Raspberry Pi 4 に OS を書き込んで電源を入れた後の詳細な操作手順です．

---

### Step 1: Raspberry Pi 4 へのログイン（接続）

接続方法は以下の 2 通りがあります：

#### A. 画面・キーボードを接続している場合（直接操作）
1. Raspberry Pi 4 の Micro HDMI ポートにディスプレイ，USB ポートにキーボードを接続します．
2. 画面にログインプロンプト（またはデスクトップ画面）が表示されたら，OS 書き込み時に設定した **ユーザー名** と **パスワード** でログインします．

#### B. 画面を接続していない場合（PC から SSH 遠隔接続）
1. PC（Windows / Mac）のコマンドプロンプトまたは PowerShell を開きます．
2. 以下のコマンドを入力して SSH 接続します：
   ```bash
   ssh <設定したユーザー名>@raspi-gse.local
   # 例: ssh pi@raspi-gse.local または ssh pi@192.168.x.x
   ```
3. パスワードを求められたら，Imager で設定したパスワードを入力します．

---

### Step 2: GSE 遠隔制御プログラムの配置

PC 上のプログラム（`tools/raspi_gse_control`）を Raspberry Pi 4 に転送します．

#### 方法 A: Git を使用する場合（推奨）
Raspberry Pi のターミナルでリポジトリをクローンします：
```bash
git clone <リポジトリのURL>
cd Gen6-GSE-Elec/tools/raspi_gse_control
```

#### 方法 B: Windows から SCP でファイルを直接転送する場合
Windows の PowerShell から以下のコマンドを実行して転送します：
```powershell
scp -r d:\Projects\TSRP\Gen6-GSE-Elec\tools\raspi_gse_control <ユーザー名>@raspi-gse.local:~/
```

---

### Step 3: 依存ライブラリのインストール

Raspberry Pi のターミナルで以下を実行し，必要な Python パッケージをインストールします：

```bash
cd ~/raspi_gse_control
pip3 install -r requirements.txt --break-system-packages
```
*(※ Debian Bookworm で `pip install` がブロックされる場合は `--break-system-packages` を付与します)*

---

### Step 4: デモモード（シミュレータ）での起動とデバッグ

実機マイコンが未接続でも，以下のコマンドで**デモモード**としてプログラムを起動できます：

```bash
python3 raspi_gse_control.py --demo
```

#### 起動後の画面と操作方法:
1. ターミナルに `GSE-Debug>` というコマンド入力画面が表示されます．
2. `status` と入力してエンターを押すと，現在の模擬圧熱やバルブ状態が表示されます．
3. `arm on` -> `fill` と入力すると，充填動作の擬似シミュレーションが始まります．
4. 同時に，同じ Wi-Fi に接続された PC やスマホのブラウザから `http://raspi-gse.local:5000` （または `http://<RaspberryPiのIPアドレス>:5000`）へアクセスすると，グラフィカルな画面でもリアルタイム操作・監視が可能です．

---

## 4. 自動起動サービス (Systemd) の登録（運用時）

Raspberry Pi 4 が起動すると，自動的に シリアル通信 (115200 bps) で Launch3.0 / Satellite3.0 と接続し，Web サーバー (Port 5000) を立ち上げます．

1. スマホ，タブレット，または PC を Raspberry Pi 4 と同一の Wi-Fi / LAN に接続します．
2. ブラウザで以下の URL にアクセスします：
   ```
   http://raspi-gse.local:5000   または   http://<RaspberryPiのIPアドレス>:5000
   ```
3. リアルタイムで N2O 圧力，電磁弁フィードバック，シーケンス状態が監視でき，安全装置（ARM）の解除や遠隔充填・点火・緊急停止コマンドを送信できます．

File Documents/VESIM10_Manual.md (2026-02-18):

# VESIM10 圧力センサ・システム運用マニュアル

このドキュメントでは、Gen6-GSE で使用されている圧力センサ `VESIM10` の仕組み、設定方法、校正手順、および詳細な計測ロジックについて解説します。

---

## 1. システム概要
`VESIM10` は、圧力を電流（4mA ～ 20mA）として出力する産業用センサです。
サテライトコントローラー（SatelliteController）で電圧に変換して読み取り、その計算結果をランチコントローラー（LaunchController）へ送信しています。

### 信号変換の流れ
1.  **圧力 (MPa)**: センサが物理的な圧力を感知。
2.  **電流 (mA)**: 4mA(0MPa) ～ 20mA(定格) の電流を出力。
3.  **電圧 (V)**: シャント抵抗（240Ω）を通して電圧に変換。
4.  **デジタル値**: マイコンのADC（10bit: 0～1023）で読み取り。
5.  **計算部**:
    *   ADC値を電流値(mA)に変換。
    *   1次遅れフィルタ(LPF)によるノイズ除去。
    *   ゼロ点オフセット（現場補正）の適用。
    *   校正係数（$y = ax + b$）による圧力値(MPa)の算出。

---

## 2. ゼロ点校正の重要手順
現場での電圧降下やノイズの影響を排除し、正確に 0.0MPa から計測を開始するための手順です。

> [!IMPORTANT]
> **ゼロ点校正を再度行う（やり直す）場合は、ランチコントローラーの電源を切り、数秒待ってから電源を再投入してください。**
> 
> 理由は、ランチコントローラーが起動してから **5秒後** に、自動で機体（Satellite）に対して「今の値を 0MPa とせよ」という校正要求を送る仕組みになっているためです。

### 手順
1.  配管内を **大気開放（0MPaの状態）** にします。
2.  ランチコントローラーの電源を入れます。
3.  5秒待つと、機体側で自動的に校正が完了します。
4.  操作卓の7SEGディスプレイが `0.0` を示せば準備完了です。

---

## 3. 計算ロジックの詳細 (Logic Breakdown)
`lib/VESIM10` 内部で行われている処理の詳細です。

### 3.1 ADC値 $\rightarrow$ 生の電流値 $I_{raw}$
マイコンは基準電圧5V、1024段階で電圧を読み取ります。

$$V_{in} = \frac{ADC\_Value \times 5.0}{1024} [V]$$
$$I_{raw} [mA] = \frac{V_{in}}{R_{shunt} (240.0)} \times 1000$$

### 3.2 ノイズ除去 (1次遅れフィルタ)
サンプリングごとの急激な変動を抑えるため、以下のフィルタを適用しています。
現在のフィルタ係数 $k$ は `0.2` に設定されています。

$$I_{filtered} = (1.0 - k) \times I_{old} + k \times I_{raw}$$

### 3.3 ゼロ点オフセットの適用
起動時の校正で取得された「理想の4mAからのズレ」を差し引きます。
※ $I_{offset} = \text{起動時の平均電流} - 4.0mA$

$$I_{effective} = I_{filtered} - I_{offset}$$

### 3.4 最終的な圧力算出
校正係数 $a$（傾き）と $b$（切片）を用いて圧力を出力します。

$$P [MPa] = a \times I_{effective} + b$$

*   **理論値での係数**:
    *   $a = FullScale / 16.0$
    *   $b = - (FullScale / 4.0)$
*   **高精度運用（推奨）**:
    手順8に従い、Excel等で求めた実測の係数を `LaunchController.cpp` に直接入力することで、センサ個体差を吸収できます。

---

## 4. ソフトウェア設定 (Configuration)
`LaunchController.cpp` の以下の箇所で、使用するセンサの性能を設定します。

```cpp
// LaunchController.cpp
namespace n2o {
  const float SENSOR_FS_MPa = 10.0f;                     // 使用するセンサの最大圧力
  const float CALIB_SLOPE_A = SENSOR_FS_MPa / 16.0f;     // 傾き
  const float CALIB_INTERCEPT_B = -CALIB_SLOPE_A * 4.0f; // 切片
}
```

---

## 5. シミュレーションモード (Dummy Mode)
実機がない環境でのテスト手順です。

1.  `LaunchController.cpp` 内で `communication::sendSensorDummyCurrent(12.0f)` （例：50%の圧力）を実行。
2.  システム全体が校正を無視し、理想的な 12.0mA として圧力を計算・表示します。
3.  終了時は `0.0f` を送ることで実機モードに戻ります。

---

## 6. 主要な関数リファレンス
- `getCurrent_mA()`: フィルタ適用後の電流値を取得。
- `getPressure_MPa()`: 最終的な圧力(MPa)を取得。
- `calibrateBlocking(count)`: 現場でのゼロ点オフセットを決定（ランチ起動時に自動実行）。

---

## 7. 高精度校正フロー（事前試験）
高圧ガス試験の結果を反映させる手順です。

1.  **データの記録**: 操作卓をPCに繋ぎ、シリアルモニタで `>VESIM10 Current` を確認しながら、標準圧力計の値を記録します。
2.  **Excelプロット**: 横軸に電流(mA)、縦軸に圧力(MPa)をプロットします。
3.  **係数の反映**: 得られた近似式 $y = ax + b$ の $a$ と $b$ を `LaunchController.cpp` に記入して書き込みます。
4.  **仕上げ**: 現場では「起動時の自動ゼロ点校正」に任せることで、温度や配線抵抗によるオフセットを自動で打ち消せます。

---

## 8. FAQ
**Q. ディスプレイが「- -」のままです**
A. 電流が 0.1mA 未満です。センサが抜けているか、断線しています。

**Q. 計測値が安定しません**
A. グランド(GND)の電位差や、周辺の電磁弁からのノイズを確認してください。必要に応じて `VESIM10.cpp` のフィルタ係数 $k$ を小さく（例：0.1）してください。

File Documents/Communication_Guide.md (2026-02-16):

# 通信システム解説ガイド (Satellite ↔ Launch)

このドキュメントでは、サテライトコントローラー（Satellite）で取得した圧力センサの電流値を、ランチコントローラー（Launch）へ送信する仕組みを初心者向けに解説します。

## 1. 使用している主要ライブラリ

### MsgPacketizer
- **役割**: データの「梱包」と「開封」。
- **特徴**: 複雑なバイナリデータを、ひとまとめの「パケット」にして送受信します。データの壊れ（化け）をチェックする機能も備えています。

### TaskManager
- **役割**: 「いつ、どのくらいの頻度で」処理をするかの管理。
- **特徴**: `loop()` の中で複雑なタイマー処理を書かなくても、「1秒間に2回（2Hz）送る」といったスケジュール管理が簡単にできます。

---

## 2. データの流れ（電流値の例）

### ステップ1：機体側でデータを送る (SatelliteController.cpp)

1.  **パケットの定義**: `Packet` という列挙型（リスト）に `SENSOR_CURRENT_SYNC` という名前を追加しています。これがデータの種類（ID）になります。
2.  **送信関数の作成**: `sendCurrentSync()` という関数の中で、`vesim10.getCurrent_mA()` を呼んで現在の電流を取得し、`MsgPacketizer::send()` を使って送信します。
3.  **スケジュールの登録**: `setup()` 内で「1秒間に2回、この関数を呼んでね」と `TaskManager` に頼んでいます。

```cpp
// 2Hz (1秒間に2回) で実行
Tasks.add(&communication::sendCurrentSync)->startFps(2);
```

### ステップ2：通信経路
RS485 という通信規格（Serial1）を通って、デジタル信号が地上へ届きます。

### ステップ3：地上側でデータを受け取る (LaunchController.cpp)

1.  **待ち受け（講読）の設定**: `setup()` 内で「`SENSOR_CURRENT_SYNC` というIDのデータが届いたら、この関数を動かしてね」という予約をしています（これを `subscribe` と呼びます）。
2.  **ハンドラ関数の実行**: データが届くと `onCurrentSyncReceived()` が自動的に実行されます。
3.  **表示**: 届いたデータ（`current_mA`）を、デバッグ用の黒い画面（シリアルモニタ）に出力します。

```cpp
void communication::onCurrentSyncReceived(float current_mA) {
  Serial.print(">VESIM10 Current: ");
  Serial.print(current_mA);
  Serial.println(" mA");
}
```

---

## 3. なぜこの仕組みなのか？

- **安全のため**: 実験中に機体に近づかなくても、遠隔で数値が確認できます。
- **効率のため**: 無闇に高速で送り続けると通信がパンクするため、`TaskManager` で適切な頻度（2Hz）に制限しています。
- **拡張性のため**: 新しく「温度」や「電圧」も送りたくなった場合、同じ仕組み（IDを増やして `send` と `subscribe` を書く）で簡単に追加できます。

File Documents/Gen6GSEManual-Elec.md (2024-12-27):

# 第6世代GSEマニュアル

## 配線工程
**ランチコントローラー**
1. DC12V ACアダプター を右側面に接続
2. DC12V ACアダプター を ポータブルバッテリー の ACポート へ接続
3. LANケーブル を背面に接続
4. AUXミニプラグ を左側面に接続
5. 外部スピーカーに AUXミニプラグ を接続
6. 充填確認スイッチ を左側面に接続

**サテライトコントローラー**
1. DC 12V ACアダプター を右側面に接続
2. DC12V ACアダプター を ポータブルバッテリー の ACポート へ接続
3. LANケーブル を背面に接続
4. 電磁弁ユニット接続ケーブル を背面に接続
5. 圧力センサーケーブル を背面に接続
6. こもあユニットケーブル を背面に接続
7. アンビリカルケーブル を右側面に接続

**電磁弁ユニット**
1. 電磁弁ユニット接続ケーブル を接続

## 電源入力
**ランチコントローラー**
1. ポータブルバッテリー の AC出力スイッチ をON
> [!NOTE]
> AC出力スイッチ の 白色LED が点灯する．
> 
2. ステータスパネル / INPUT が点灯していることを確認
> [!IMPORTANT]
> 点灯していない場合 DC12V ACアダプター が適切に接続できているか確認
>
> 接続直後はコンデンサが充電されていないため点灯しない．
**サテライトコントローラー**
1. ポータブルバッテリー の AC出力スイッチ をON
> [!NOTE]
> AC出力スイッチ の 白色LED が点灯する．
2. ステータスパネル の INPUT が点灯していることを確認
> [!IMPORTANT]
> 点灯していない場合 DC12V ACアダプター が適切に接続できているか確認
>
> 接続直後はコンデンサが充電されていないため点灯しない．

> [!WARNING]
> 省電力モードスイッチ を OFF にする．
> 
> GSE内にバッテリーを搭載していないため満充電したと誤解され，一定時間経過後自動で出力が OFF になる．

## 起動
**ランチコントローラー**
1. Safety を ***Safe***
2. 手動スイッチがすべて操作者側に倒れていることを確認
3. 主電源ON を右に回し続ける
4. すべてのLEDが点灯していることを確認
5. 主電源ON LED が点灯していることを確認
6. ステータスパネル / 12V が点灯していることを確認
7. ステータスパネル / 5V が点灯していることを確認
8. ステータスパネル / LOW が消灯していることを確認
9. ステータスパネル / TASK が点滅していることを確認
10. ステータスパネル / COM が点滅していることを確認
> [!WARNING]
> 点灯しない LED がある場合は電装系出勤
> 
> ステータスパネル / POWER の動作が手順書と異なる場合はトラブルシュート
>
> ステータスパネル / COM が点滅していない場合は LANケーブル を適切に接続する

> [!NOTE]
> LOW = Low Voltage, COM = Communication
 
**サテライトコントローラー**
1. Safety を ***Safe***
2. 手動スイッチがすべて操作者側に倒れていることを確認
3. 主電源ON を右に回し続ける
4. すべてのLEDが点灯していることを確認
5. 主電源ON LED が点灯していることを確認
6. ステータスパネル / 12V が点灯していることを確認
7. ステータスパネル / 5V が点灯していることを確認
8. ステータスパネル / LOW が消灯していることを確認
9. ステータスパネル / TASK が点滅していることを確認
10. ステータスパネル / COM が点滅していることを確認
> [!WARNING]
> 点灯しない LED がある場合は電装系出勤
> 
> ステータスパネル / POWER の動作が手順書と異なる場合はトラブルシュート
>
> ステータスパネル / COM が点滅していない場合は LANケーブル を適切に接続する

> [!NOTE]
> LOW = Low Voltage（低電圧）, COM = Communication（通信）

## 操作確認
**ランチコントローラー**
1. Safety を ***Armed***

**サテライトコントローラー**
1. Safety を ***Armed***

**ランチコントローラー**
1. FILLスイッチ ON -> OFF
2. DUMPスイッチ ON -> OFF
3. O<sub>2</sub>スイッチ ON -> OFF
4. IGNスイッチ ON -> OFF
5. PURGEスイッチ ON -> OFF
>[!IMPORTANT]
> オレンジLED 点灯 と グリーンLED 点灯で合格
> 
> 現状は電磁弁ユニットに人をつけ音を聞く

> [!NOTE]
> IGN = IGNition

6. エマージェンシーストップ ON
> [!IMPORTANT]
> PURGE ON と MainOPEN の信号カット(=MainCLOSE) と DUMP の信号カット（=DumpOPEN）
> 
> で合格

7. DUMPスイッチ ON
8. シークエンス開始 ON
> [!IMPORTANT]
> ハトと少年再生で合格

9. DUMPスイッチ OFF
10. Safety を ***Safe***

**サテライトコントローラー**
1. Safety を ***Safe***

## 酸化剤放出試験
**空圧弁ユニット**
1. 切替弁を CLOSE

**サテライトコントローラー**
1. Safety を ***Armed***
2. 退避

**ランチコントローラー**
1. 保安位置確認，終了していれば保安の継続通達
2. Safety を ***Armed***
3. 酸化剤放出試験を行うことを告知
4. FILLスイッチを 2.0 sec 程度 ON
5. Safety を ***Safe***

> [!IMPORTANT]
> FILL の空圧弁はスイッチを押してからおよそ 0.7 sec 後に OPEN

酸化剤放出試験完了

## シークエンス開始
1. 切替弁を OPEN

**サテライトコントローラー**
1. Safety が **Armed** になっていることを確認
2. こもあに AC 100V を接続
2. 退避

**ランチコントローラー**
1. Safety を **Armed**
2. 充填確認スイッチ を持つ
   - PM
   - GSE責任者
   - 燃焼班長
3. DUMPスイッチ を ON
4. シークエンス開始
5. 充填を確認したら 充填確認スイッチ をON

## 燃焼実験後
1. PURGEスイッチ を ON
2. シークエンス開始 を押しリセット
   - Mainバルブ CLOSE
3. DUMPスイッチ OFF

## 脱圧
1. 保安を継続
2. DUMPスイッチ OFF
3. 30 sec 程度 DUMP 開放

**ランチコントローラー**
1. Safety を ***Safe***

**ボンベ**
1. N<sub>2</sub>O ボンベを閉栓
2. O<sub>2</sub> ボンベを閉栓

**空圧弁ユニット**
1. 切替弁を CLOSE
2. 退避

**ランチコントローラー**
1. Safety を ***Armed***
2. FILLスイッチ を ON し続ける

**ボンベ**
1. 目視で N<sub>2</sub>O ボンベ圧力が0になっていることを確認

**ランチコントローラー**
1. Safety を ***Safe***

**サテライトコントローラー**
1. Safety を ***Safe***

保安解除

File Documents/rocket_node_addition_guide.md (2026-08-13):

# ロケット搭載用子機（RocketNode）を追加する実装手順書

このドキュメントでは、RS-485通信（MsgPacketizer）によるポーリング方式を維持したまま、**3台目の子機（ロケット搭載用ノード：RocketNode）を追加し、イグニッション（IGNITER）およびメインバルブ開（OPEN）の制御状態を送信・同期する**ための具体的な実装方法をまとめます。
また、ロケットの発射に伴いケーブルが離脱（通信断）することを前提とし、**通信途絶時のエラー処理（フェールセーフ発動）は行わず、単なる通知に留める**仕様とします。

---

## 1. 全体設計

ポーリング方式では、「親機が順番に指名し、指名された子機のみが返事をする」というルールを守ります。
現在、親機は2台の機器を交互に指名していますが、これを**3台の機器を順番に指名する状態遷移**に拡張します。

```mermaid
graph TD
    A[LaunchController] -->|1. 指名 & 命令送信| B(SatelliteController)
    B -->|返信| A
    A -->|2. 指名 & 生存確認| C(SatelliteNode)
    C -->|返信: スイッチ状態| A
    A -->|3. 指名 & イグニッション・オープン状態送信| D(RocketNode)
    D -->|返信: 生存確認| A
```

---

## 2. 実装手順（親機：LaunchController側）

### ① パケットID（Packet Enum）の定義追加
`LaunchController2.0.cpp` 内の `communication::Packet` 列挙体に、ロケットノード用のパケットIDを追加します。

```cpp
namespace communication
{
  enum class Packet : uint8_t
  {
    // ... 既存の定義 ...
    LIMIT_SWITCH_SYNC = 10,
    COM_CHECK_L_TO_N = 11,
    COM_CHECK_N_TO_L = 12,

    // ★新規追加
    COM_CHECK_L_TO_RN = 13,       // 親機 ➔ ロケットノード 生存確認
    COM_CHECK_RN_TO_L = 14,       // ロケットノード ➔ 親機 生存確認
    ROCKET_NODE_STATE_SYNC = 15,  // 親機 ➔ 状態同期（イグニッション/OPEN状態）
  };
}
```

### ② タイムアウト管理変数とフラグの追加
ロケットノードの生存確認を監視するための変数を用意します。また、離脱したことを一度だけ通知するためのフラグも用意します。

```cpp
namespace communication
{
  // ... 既存の定義 ...
  unsigned long preReceivedTime_Node = 0;
  
  // ★新規追加
  unsigned long preReceivedTime_RocketNode = 0; 
  bool isRocketNodeDisconnected = false; // 離脱検知済みフラグ
}
```
`setup()` 内で `communication::preReceivedTime_RocketNode = millis();` として初期化しておきます。

### ③ ポーリングタスク（pollingTask）の拡張（3択へ）
現在交互に切り替えている処理を、3つの状態をローテーションするように変更します。また、ロケットノードのターンで `IGNITER`（`control::igniter.isRaised()`）および `OPEN`（`control::open.isRaised()`）の状態を1バイトにまとめて送信します。

```cpp
void communication::pollingTask()
{
  static uint8_t pollTarget = 0; // 0: Controller, 1: SatelliteNode, 2: RocketNode

  if (pollTarget == 0)
  {
    // ----------------------------------------------------
    // 1. SatelliteController への送信
    // ----------------------------------------------------
    // ... 既存コード ...
  }
  else if (pollTarget == 1)
  {
    // ----------------------------------------------------
    // 2. SatelliteNode への送信（生存確認）
    // ----------------------------------------------------
    // ... 既存コード ...
  }
  else if (pollTarget == 2)
  {
    // ----------------------------------------------------
    // 3. ロケットノード（RocketNode）への送信（状態同期 ＆ 生存確認）
    // ----------------------------------------------------
    // IGNITER（イグニッション）と OPEN（オープン）の状態を取り出し、ビットに割り当てる
    // Bit0: IGNITER (1=ON / 0=OFF)
    // Bit1: OPEN (1=ON / 0=OFF)
    uint8_t syncState = 0;
    if (control::igniter.isRaised()) syncState |= (1 << 0);
    if (control::open.isRaised()) syncState |= (1 << 1);

    communication::enableOutput();
    // 状態データと、呼びかけ（COM_CHECK）を送信
    MsgPacketizer::send(Serial1, static_cast<uint8_t>(communication::Packet::ROCKET_NODE_STATE_SYNC), syncState);
    MsgPacketizer::send(Serial1, static_cast<uint8_t>(communication::Packet::COM_CHECK_L_TO_RN));
    Serial1.flush(); // （環境により flush のフリーズ対策が必要な場合は delay に変更）
    communication::disableOutput();
  }

  // ターゲットを 0 ➔ 1 ➔ 2 ➔ 0 ... とローテーションする
  pollTarget = (pollTarget + 1) % 3;
}
```

### ④ 受信コールバックの登録
親機の `setup()` でロケットノードからの返信（`COM_CHECK_RN_TO_L`）を受けるコールバックを登録します。

```cpp
// ロケットノードからの生存確認パケット受信時の処理
void communication::onComCheckRocketNodeReceived()
{
  communication::preReceivedTime_RocketNode = millis(); // 時刻を更新
  
  if (communication::isRocketNodeDisconnected) {
      communication::isRocketNodeDisconnected = false;
      Serial.println("[INFO] RocketNode Connected");
  }
}
```

`setup()` 内に登録コードを追加します。
```cpp
MsgPacketizer::subscribe(
    Serial1, static_cast<uint8_t>(communication::Packet::COM_CHECK_RN_TO_L),
    &communication::onComCheckRocketNodeReceived);
```

### ⑤ エラー処理を「行わず通知のみ」にする
フェールセーフ関数 `communication::onComCheckFailed()` において、ロケットノードのタイムアウト時は**エラー状態（赤色ランプ等）に遷移させず、単なるシリアル通知のみ**とします。

```cpp
void communication::onComCheckFailed()
{
  bool controllerTimeout = (millis() - communication::preReceivedTime > communication::timeout);
  bool nodeTimeout = (millis() - communication::preReceivedTime_Node > communication::timeout);
  
  // ロケットノードのタイムアウト判定
  bool rocketNodeTimeout = (millis() - communication::preReceivedTime_RocketNode > communication::timeout);

  // 既存のノード（ControllerとSatelliteNode）がタイムアウトした場合は致命的エラー
  if (controllerTimeout || nodeTimeout)
  {
    communication::statusLamp.off();
    error::statusLamp.on();
    // ... エラー時の安全処理 ...
  }
  
  // ロケットノードがタイムアウトした場合はエラーにせず、通知のみ行う
  if (rocketNodeTimeout && !communication::isRocketNodeDisconnected)
  {
    communication::isRocketNodeDisconnected = true;
    Serial.println("[INFO] RocketNode Disconnected (Umbilical Released)");
  }
}
```

---

## 3. 実装手順（子機：RocketNode側）

ロケットノード側のプログラムでは、話しかけられた時の返信と、受け取ったデータのパースを行います。

```cpp
#include <Arduino.h>
#include <MsgPacketizer.h>

enum class Packet : uint8_t {
  COM_CHECK_L_TO_RN = 13,
  COM_CHECK_RN_TO_L = 14,
  ROCKET_NODE_STATE_SYNC = 15,
};

// 親機から送られてきた状態を保存する変数
bool isIgniterActive = false;
bool isOpenActive = false; // 適当に isOpenActiveって書いてる

// 状態データ受信時のコールバック
void onStateSyncReceived(uint8_t syncState) {
  isIgniterActive = (syncState >> 0) & 0x01; // Bit0からIGNITERの状態を抽出
  isOpenActive    = (syncState >> 1) & 0x01; // Bit1からOPENの状態を抽出

  // 受信した情報をそのままCANに流す
  // 1. イグニッション状態の送信
  can.sendIgnition(isIgnitionActive);

  // 2. メインバルブの状態の送信
  can.sendValveMode(isOpenActive); // 適当に isOpenActiveって書いてる
}

// 親機からの生存確認受信時のコールバック
void onComCheckReceived() {
  // 親機に対して「生きてるよ！」の返事を即座に返す
  // （※RS485モジュールの送受信切り替えピン DERE の制御）
  digitalWrite(PIN_RS485_DERE, HIGH); 
  MsgPacketizer::send(Serial1, static_cast<uint8_t>(Packet::COM_CHECK_RN_TO_L));
  Serial1.flush();
  delay(2);
  digitalWrite(PIN_RS485_DERE, LOW);  
}

void setup() {
  Serial1.begin(115200);
  pinMode(PIN_RS485_DERE, OUTPUT);
  digitalWrite(PIN_RS485_DERE, LOW); // 初期状態は受信モード

  // コールバックの登録
  MsgPacketizer::subscribe(Serial1, static_cast<uint8_t>(Packet::ROCKET_NODE_STATE_SYNC), &onStateSyncReceived);
  MsgPacketizer::subscribe(Serial1, static_cast<uint8_t>(Packet::COM_CHECK_L_TO_RN), &onComCheckReceived);
}

void loop() {
  MsgPacketizer::parse(); // 通信データの解析
}
```

---

## 4. 動作確認と注意点

1. **離脱時の挙動：**
   ロケットが打ち上がりケーブル（アンビリカル）が抜けると通信が途絶え、LaunchController側で `rocketNodeTimeout` が `true` になります。このときシステム異常停止（フェールセーフ）は発生せず、シリアルモニタに `[INFO] RocketNode Disconnected (Umbilical Released)` が出力されるだけになります。
2. **パケットIDの競合：**
   `LaunchController` と `RocketNode` 間で `Packet` の番号（13, 14, 15）が完全に一致していることを確認してください。

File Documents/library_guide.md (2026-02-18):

# 通信・タスク管理ライブラリについて

本プロジェクト（Gen6-GSE-Elec）では、通信とタスク管理の効率化のために [hideakitai](https://github.com/hideakitai) 氏制作のライブラリを採用しています。
AVRマイコン（ATmega2560）で使用する際の**「独特な制約（落とし穴）」**と、その対処法についてまとめます。

---

## 1. MsgPacketizer（通信ライブラリ）
### 概要
RS485などのシリアル通信で、複雑なデータ（数値、配列など）を「パケット」として安全・簡単に送受信するためのライブラリです。

### 初心者がハマるポイント (AVR限定)
AVRマイコン（ATmega2560）ではメモリ節約のため、**「何種類のデータを受け取るか」**などの上限が非常に小さく設定されています。

| 項目 | デフォルト | 意味 | 制限を超えると... |
| :--- | :---: | :--- | :--- |
| **subscribe数** | **3** | `MsgPacketizer::subscribe` で登録できるIDの種類 | 4つ目以降の登録が**無視**され、通信が届かない。 |
| **Arrayサイズ** | **3** | 1つのパケットに詰め込める変数の個数 | 4つ以上のデータを送ろうとすると、受信側で失敗する。 |
| **パケットサイズ** | **96B** | 1パケットの最大バイト数 | 長すぎるデータは送信・受信できない。 |

### 対処法 (`platformio.ini`)
制限を増やしたい場合は、プロジェクトの設定ファイルに「上限を上書きする指示」を書きます。
```ini
build_flags = 
    -D PACKETIZER_MAX_CALLBACK_QUEUE_SIZE=8  ; subscribe数を8に拡大
    -D MSGPACK_MAX_ARRAY_SIZE=10             ; パケット内の変数個数を10に拡大
```

---

## 2. TaskManager（タスク管理ライブラリ）
### 概要
「1秒ごとにセンサ値を読む」「10Hzで通信を送る」といった複数の処理（タスク）を、`delay()` を使わずに「並行して動いているように」管理するライブラリです。

### 初心者がハマるポイント (AVR限定)
こちらもAVRマイコンでは、登録できるタスクの数に上限があります。

| 項目 | デフォルト | 意味 | 制限を超えると... |
| :--- | :---: | :--- | :--- |
| **メインタスク数** | **16** | `Tasks.add()` で登録できるタスクの総数 | 17個目のタスクが**起動しない**。 |
| **サブタスク数** | **4** | タスクの中でさらに `add` する際の上限 | 複雑な親子タスクを作る際に失敗する。 |

### 対処法 (`platformio.ini`)
シーケンス処理などを増やしてタスクが足りなくなった場合は、以下の指示を追加します。
```ini
build_flags = 
    -D ARX_VECTOR_DEFAULT_SIZE=32      ; タスク上限を32に拡大
    -D TASKMANAGER_MAX_SUBTASKS=8      ; サブタスク上限を8に拡大
```

---

## 3. ボードによる違い（重要）
この制約は、**「メモリの少ない古いマイコン（AVR）」**でのみ発生します。

*   **ATmega2560 など**: **上記制限あり**。`build_flags` で調整が必要。
*   **RA4M1 など**: **制限なし**。モダンな設計のため、メモリの許す限り自動で増えます。

## まとめ
「コードは間違っていないのに、なぜか通信が届かない・タスクが動かない」という時は、まず上記の **デフォルト上限** を疑ってください。基本的には `build_flags` で余裕を持った数値に設定しておくのが安全です。

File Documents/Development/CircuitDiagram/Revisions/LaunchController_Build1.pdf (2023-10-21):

PO•" | 皿",I<. f' l
'.~: ー：＇三,, | '"

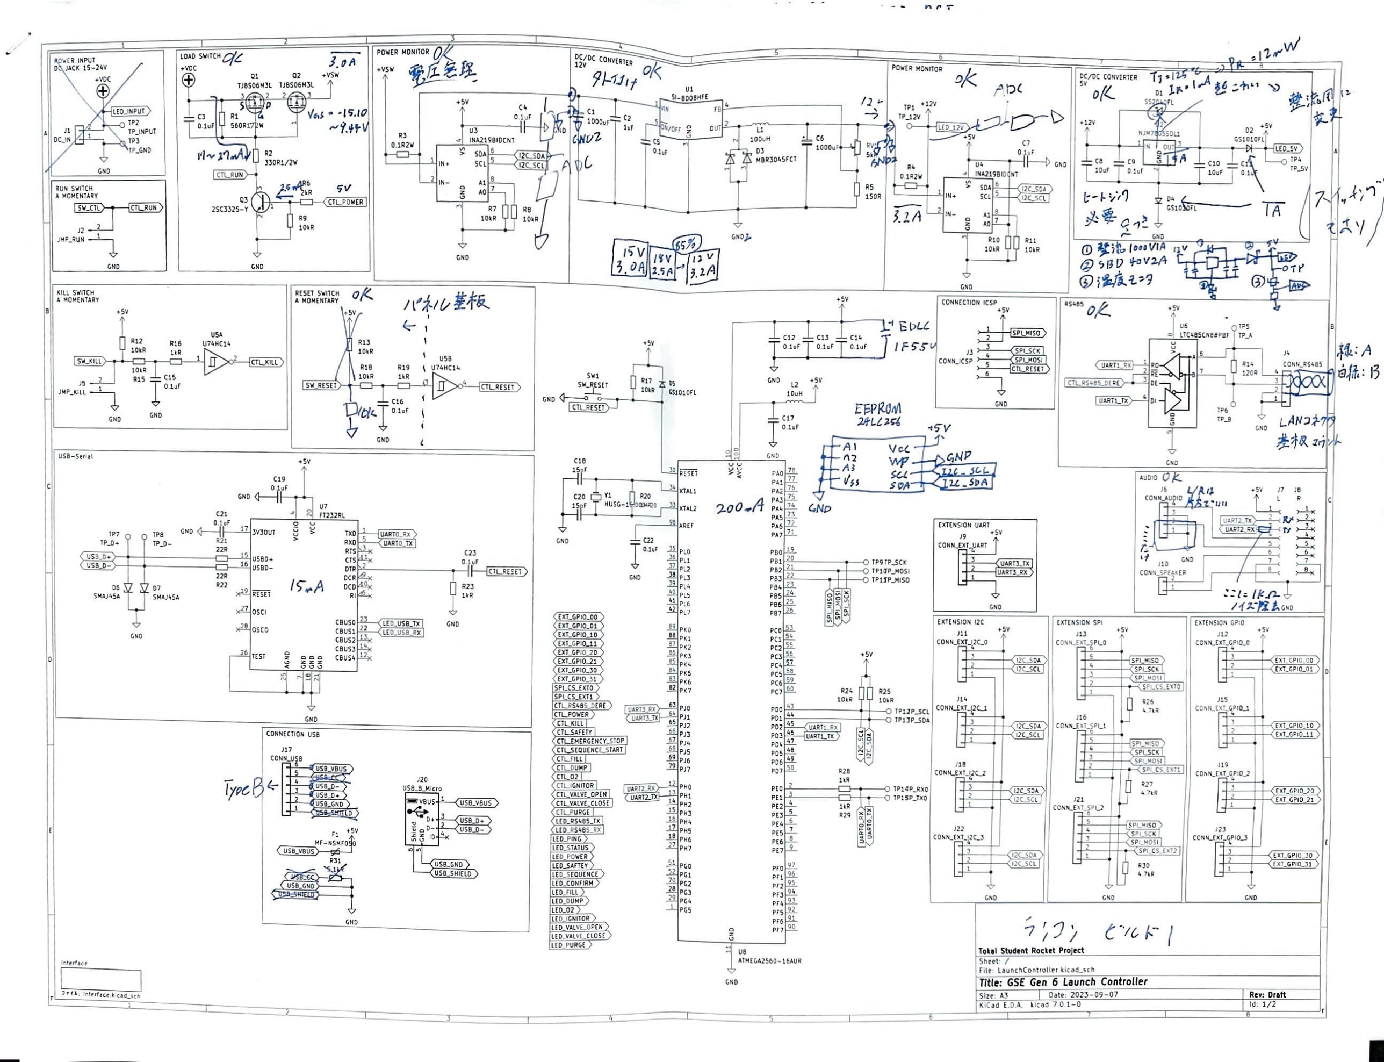
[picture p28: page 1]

"" """"' "'""

, .. ,, v.J

儡

m" 99

ぷ

<;II

### C1L.POS£R

.,_: コ'"'

▲ r

悶 土← | 30

'"

USB-S● '' | .s,

C19
1,f

'"臼＇ i

## 戸 ,-,j_fヤ

：『巧

界認忠 | /( | ネレ差枝
←一 ，＇
CC/DC cow; 叩• | i., 乃-
/( | J_ ,- •I | ;.ti ゞ ····•· ●， | ク | 移 . ,

# I "'五、し

# 竺""'下 ェTCID'"' 了" L

ピト況・（り | 1
廷 | ぇlZぶ。← T
~ | .. の父池 . , (j) 砂 ゃ

准(#...む？

U7 凸ら"゜五2211 | 二刊二
匹 | 屯 | y:;., ,,

"'

"'

### CO血 CCTIO, SS

l7/?c.
" ,,
写
皐叩

m
Olof 日 CILRmt)
"'
い

。ー 。， L

f | い

了
笠會

ヽ

に

c a" 。

""'

# [「ー／／ヽーソ

## ＂ィ什 ，々

廿
れ

7

.,v

# ＾ " B以上

# ふ / IF>.>

## 即閲 211-LO~

""',t.

·• ヽ J7 "

~ ,-1..

## rt ,-...2.c

' "'"L~

’｀゜ | '"' 7 | / | クヽ／

VO
'1HCG'2500-1"VR

("I(., ド／
□
"●'"'
1 ・''"""'""ぶ＾ | '"'

### - I Studo,t Rocht P<0tct

# '"'I Tltl

,,t:

# '"""""'"'『""'-'" E Gtn 6 Launh Controller

"" ,., I " 2023-09-07 <IC• d t.O•- llcod 7 O -0
R,., <ott
Id. 1/2

1~b:. ~t-/I'F1 | ＇ LbD P..H iY c, Fl M | う | ;rtJ r • f1 /"I "'I r '
'" | と

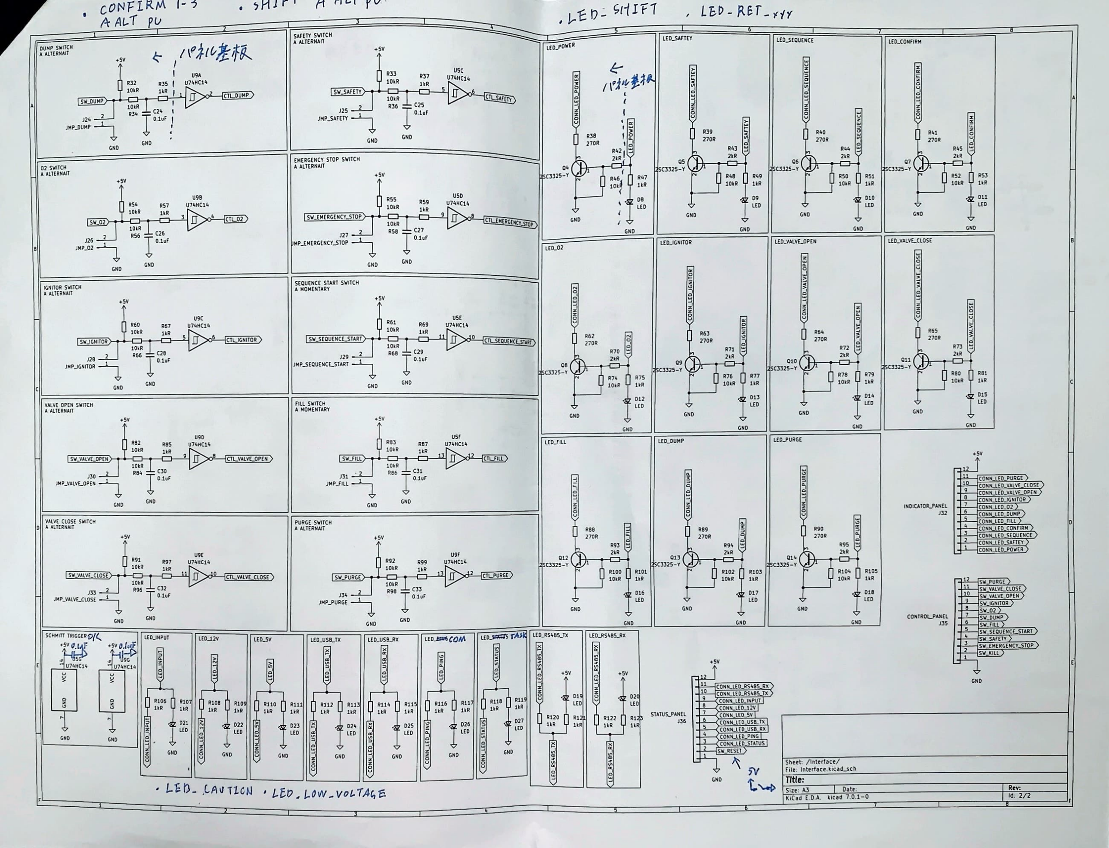
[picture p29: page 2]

A じ pu | 匝年CY | II [O..S[● U!NCE | 1 UO_(ONrlRM SAf(lY SWITCH

A AL.TERNA『

# /¥。加彦柊、

~"' | use | II 后
れが

I;:- I

Rl) | 111' ur••
,, | I u ...
— | }25 _L..J | ftU | L~-.
・一 ↓ ゜,,! | JHP..SIJ[TY ~

MPJJU,,. MP~:
ヽND
"' '"
- ,
疇江|匹ぴ『'-~µ::: nm-r | "' | "'

『 ⁽M[RCCNCY STOP S'r/lTCH

C,325-T •• | .., ●● | "' | D10 | UD OU

A ALTUNAIT
•IY
9 | 匹

1'

●● | LCD | 、●●

02 llllCH
"' | . .,
l llT[RMAll | .,
"' '"' | , ~ | '" llw_mvUPE• | I I llD_VALVLCLDSt

l(D_02
.i, | ""
'"' | II GNO

IC,HITOA SV!TC H 贔 ALT[i NJJ T

II 510NQ,!NN[NC[ • | 贔51""1 ITCH

↓ | ↓ | lll5 | R7S | 176 | R77 | 1UI | 1ou | R
.. CiHD | UR | 10tlt | Hit
, | '"'"
I •P..sEOUENCLSImARI ~___1.., | --Tot,r | 0 , | °'"0-9 '"" | omO-to , 冒"' 「μ ● " I ！ '" 012 | 、 Oil | UD | UO

I I

V.&L~[ OP[ N S'lilTCN | 贔
『IllNON[NTART SVITCH | UO | t.ND | LCD | 、MO
贔 .&I.T(RNA』 | 、ND
·• c,• ~ D ' "皿.... II | """'1.言..~ I 皿 | 竺— II~ 叩~ ... | I ••石石 、● | 』••
"凡 LVLOPE"' • ...J..._'↓ " " | ' | O | N | O "'I liu, l | 11 | l~V l | 11~V | """'0'-'唸
1•11 芯瞬'""" | II~ 靡，茄CH | I
.,v | '↑ " | II 1- :- ~ II "'~ 沃ぶ— 苔『 』。"忠● 10J

"'

叫,.. 心 ""7 | HP.J'URGC7 | ↓ | ON | ↓ | , ND | ↓ IIONO | V | C0,!1t0LIハCl
u,r | I ,,. _.__, "" T , 『 | I ↓ | 呼ば I I ↓ | ’乎盟
、NO | C.NO | C.NO | C.NO | 、NO | C.NO | C.ND | 』35
"""'"'"""0(llm」"'"'I | ~ >~~ 「"ー;;・拿 : Ill ·d ·: I " c...: 「臼•

# I I ~,,, LJ

I, ...
.. ,. LJ
/., ●
_
1 11 /., "" よ.. l "鼻,.,._,. "' j'J 1 ... 1 -~ ぎ そ | LIO
ヽ"ヽ" | 111叫. l. I

Shut・/lntrrtacr/
Fitt. lnttrf● Ct iudJch
CiHO | if" | Titie: | 曾：
"' | I | I...) | L.,'¥...,f> S1 : AJ | 山 ． | Id 2 • 1-~I'.)- lMHGI.I 、t.E. ヽt.ow_ し1.4咋 | ，， ヽd£DA. ヽ"●d 7 1-0 | 」 /2

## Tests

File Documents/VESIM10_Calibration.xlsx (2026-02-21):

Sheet: 20260221_1
試験日 | 2026-02-21 | 圧力媒体 | 精製水 | 窒素
 |  |  |  | 酸素
No. | 電流 [mA] | マスタ圧力計 [MPa] |  | 亜酸化窒素
1 | 4.08 | 0 |  | 精製水
2 | 6.08 | 1.2
3 | 7.95 | 2.3
4 | 10.20 | 3.6
5 | 12.60 | 4.74
6 | 14.20 | 6
代入→ | CALIB_SLOPE_A | 0.5777
 | 理論値 | 0.625

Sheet: 試験成績表
試験日 | 2024-01-18 | 使用した高圧ガス | 不明 | 窒素
 |  |  |  | 酸素
No. | 電流 [mA] | マスタ圧力計 [MPa] |  | 亜酸化窒素
1 | 3.99 | 0 |  | 精製水
2 | 11.97 | 5 |  | 不明
3 | 20.02 | 10
4
5
6
代入→ | CALIB_SLOP_A | 0.6238
 | 理論値 | 0.625

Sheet: テンプレート
試験日 |  | 使用した高圧ガス | 窒素
 |  |  | 酸素
No. | 電流 [mA] | マスタ圧力計 [MPa] | 亜酸化窒素
1 | 4.08 | 0 | 精製水
2 | 7.25 | 2.1
3 | 10.42 | 4.2
4 | 13.58 | 5.8
5 | 16.74 | 8.2
6 | 19.91 | 9.9

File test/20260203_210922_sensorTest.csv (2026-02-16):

FRAM ID: 4 7F 4A 81
Time_ms | adxl_x | adxl_y | adxl_z | icm_acc_x | icm_acc_y | icm_acc_z | icm_gyro_x | icm_gyro_y | icm_gyro_z
12.94 | 4.81 | 10.09 | 20.66 | 0.03 | 0.01 | 1.03 | -0.06 | -0.24 | -0.24
12.95 | 7.21 | 6.73 | 25.95 | 0.03 | 0.00 | 1.03 | -0.06 | -0.24 | -0.18
12.97 | -2.40 | 6.25 | 19.22 | 0.02 | 0.01 | 1.03 | -0.06 | -0.18 | -0.18
12.98 | -0.48 | 4.81 | 18.26 | 0.03 | 0.01 | 1.03 | -0.06 | -0.31 | -0.24
12.99 | -11.53 | 4.32 | 25.95 | 0.03 | 0.01 | 1.03 | -0.06 | -0.24 | -0.24
13.01 | 3.84 | 10.57 | 14.90 | 0.03 | 0.00 | 1.03 | -0.12 | -0.24 | -0.24
13.02 | 4.81 | 2.88 | 21.14 | 0.03 | 0.00 | 1.03 | -0.12 | -0.31 | -0.18
13.03 | -6.73 | 9.13 | 22.10 | 0.03 | 0.00 | 1.03 | -0.06 | -0.24 | -0.18
13.05 | 1.92 | 8.65 | 22.58 | 0.03 | 0.01 | 1.03 | -0.06 | -0.24 | -0.18
13.06 | -0.96 | 5.77 | 14.42 | 0.03 | 0.00 | 1.03 | -0.12 | -0.24 | -0.18
13.07 | -0.48 | 3.36 | 19.70 | 0.03 | 0.00 | 1.03 | -0.06 | -0.24 | -0.12
13.08 | 0.96 | 11.53 | 29.79 | 0.03 | 0.00 | 1.03 | -0.12 | -0.24 | -0.18
13.10 | 0.00 | 1.92 | 17.78 | 0.03 | 0.01 | 1.03 | -0.12 | -0.24 | -0.18
13.11 | 2.40 | 3.84 | 24.51 | 0.03 | 0.01 | 1.03 | 0.00 | -0.24 | -0.12
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

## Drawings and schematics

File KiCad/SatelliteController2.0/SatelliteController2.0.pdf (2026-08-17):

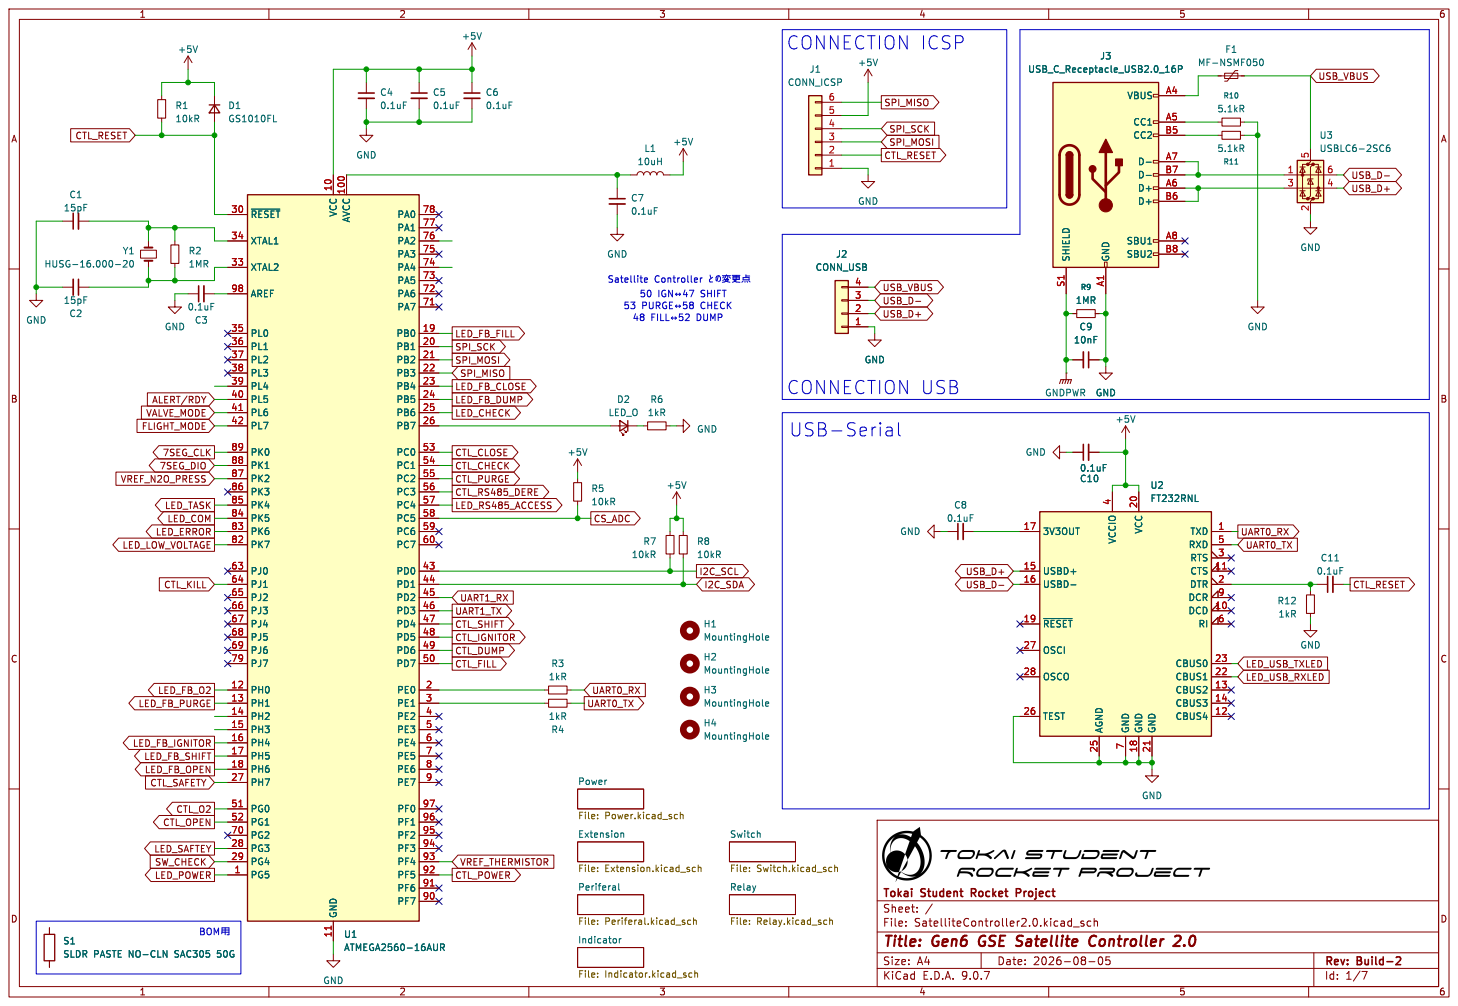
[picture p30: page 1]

7 VCC 20 GND 18 GND 21 TXD 1 RXD 5 RTS 3 CTS 11 DTR 2 DCR 9 DCD 10 RI 6 CBUS0 23 CBUS1 22 CBUS2 13 CBUS3 14 CBUS4 12 U2 FT232RNL C10

7 VCC 20 GND 18 GND 21 TXD 1 RXD 5 RTS 3 CTS 11 DTR 2 DCR 9 DCD 10 RI 6 CBUS0 23 CBUS1 22 CBUS2 13 CBUS3 14 CBUS4 12 C10

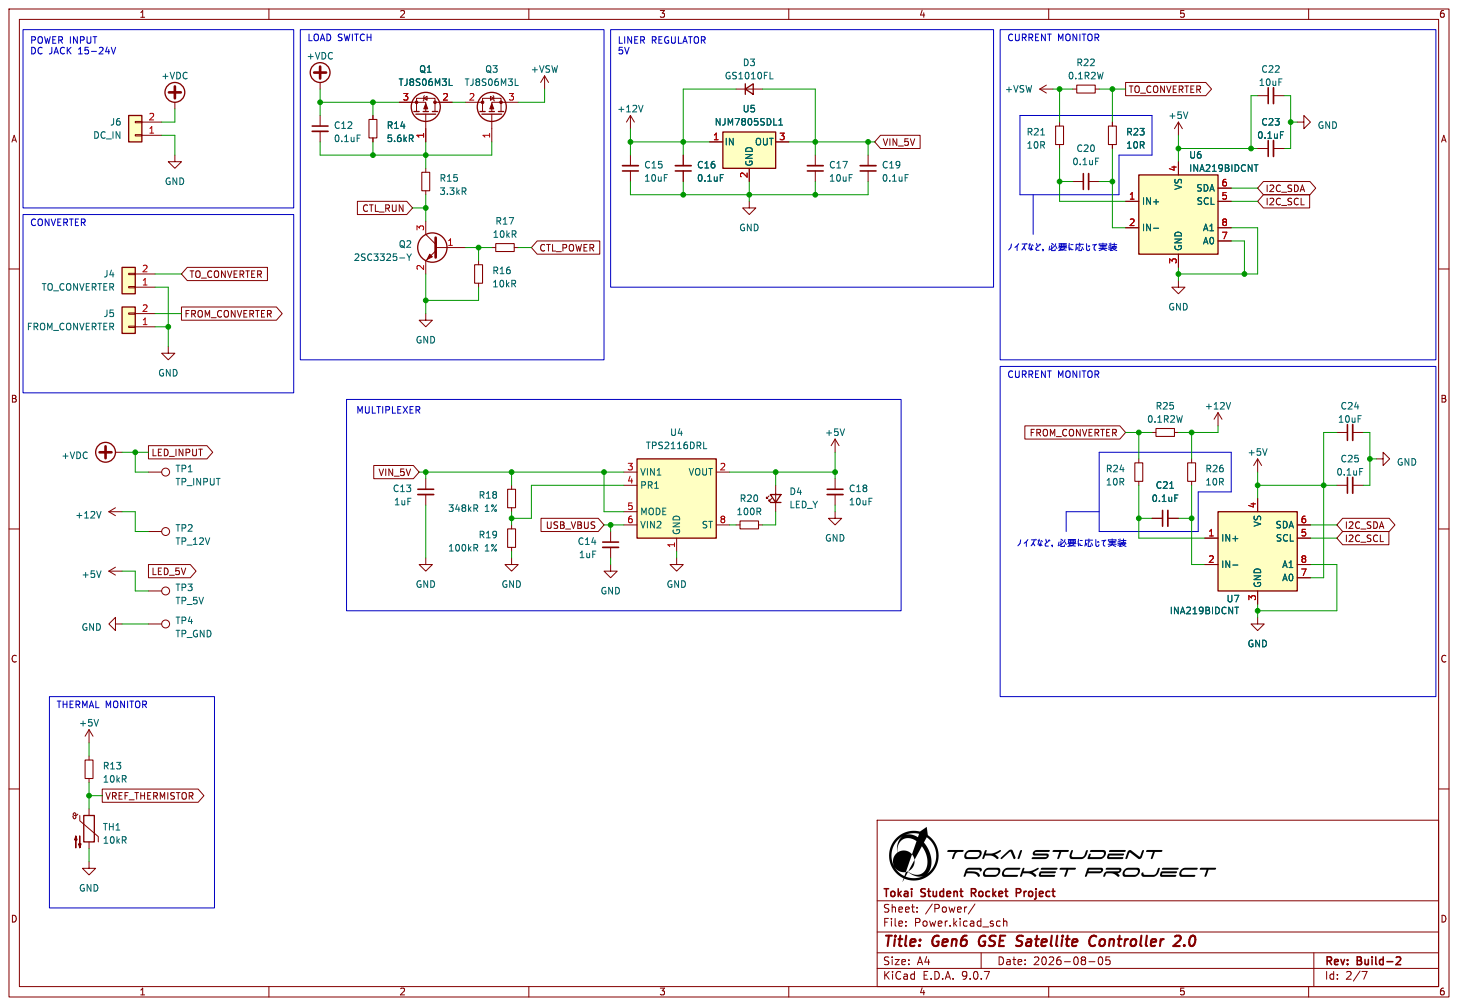
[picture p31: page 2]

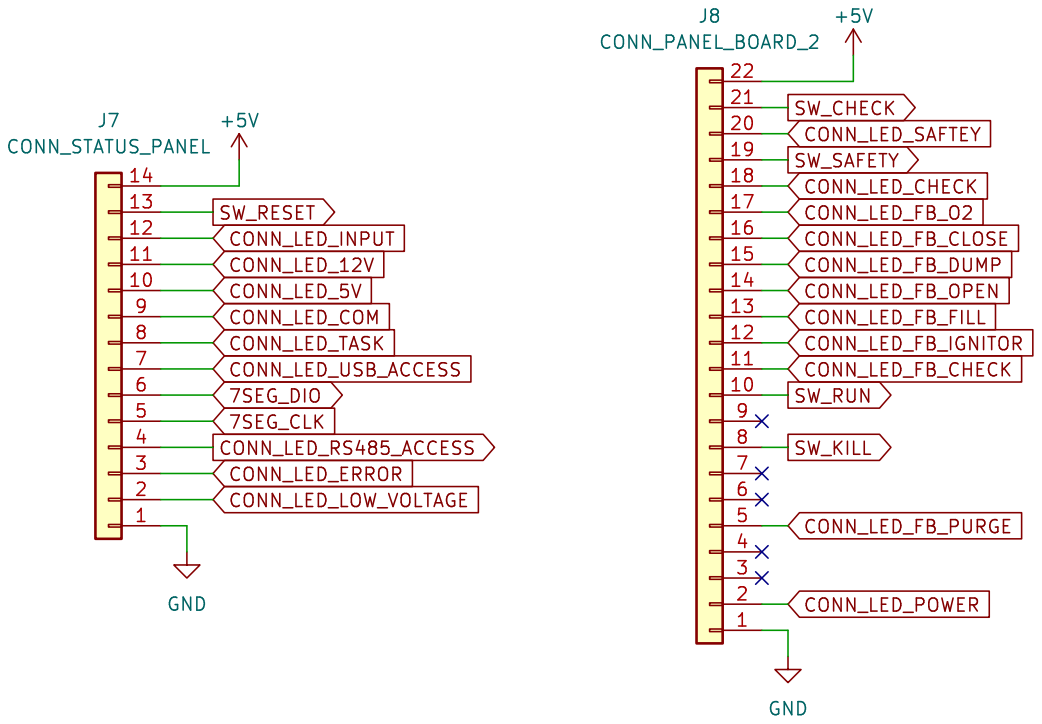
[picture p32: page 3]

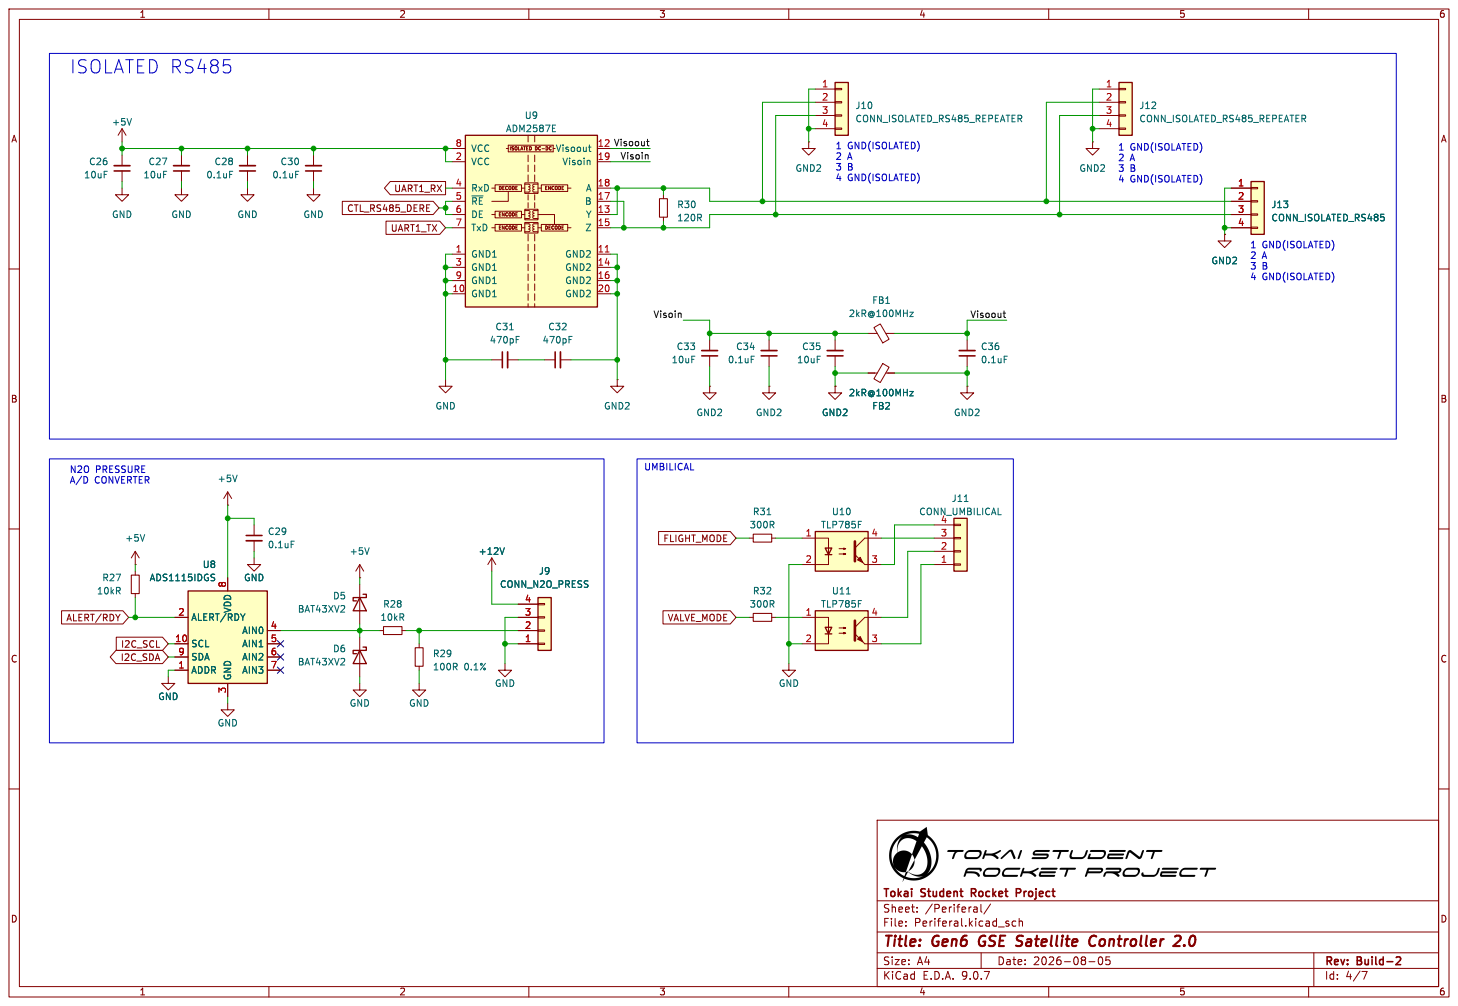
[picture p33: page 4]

3 ALERT/RDY 2 SCL 10 SDA 9 ADDR 1 FB2

3 ALERT/RDY 2 SCL 10 SDA 9 ADDR 1 U8 ADS1115IDGS C29

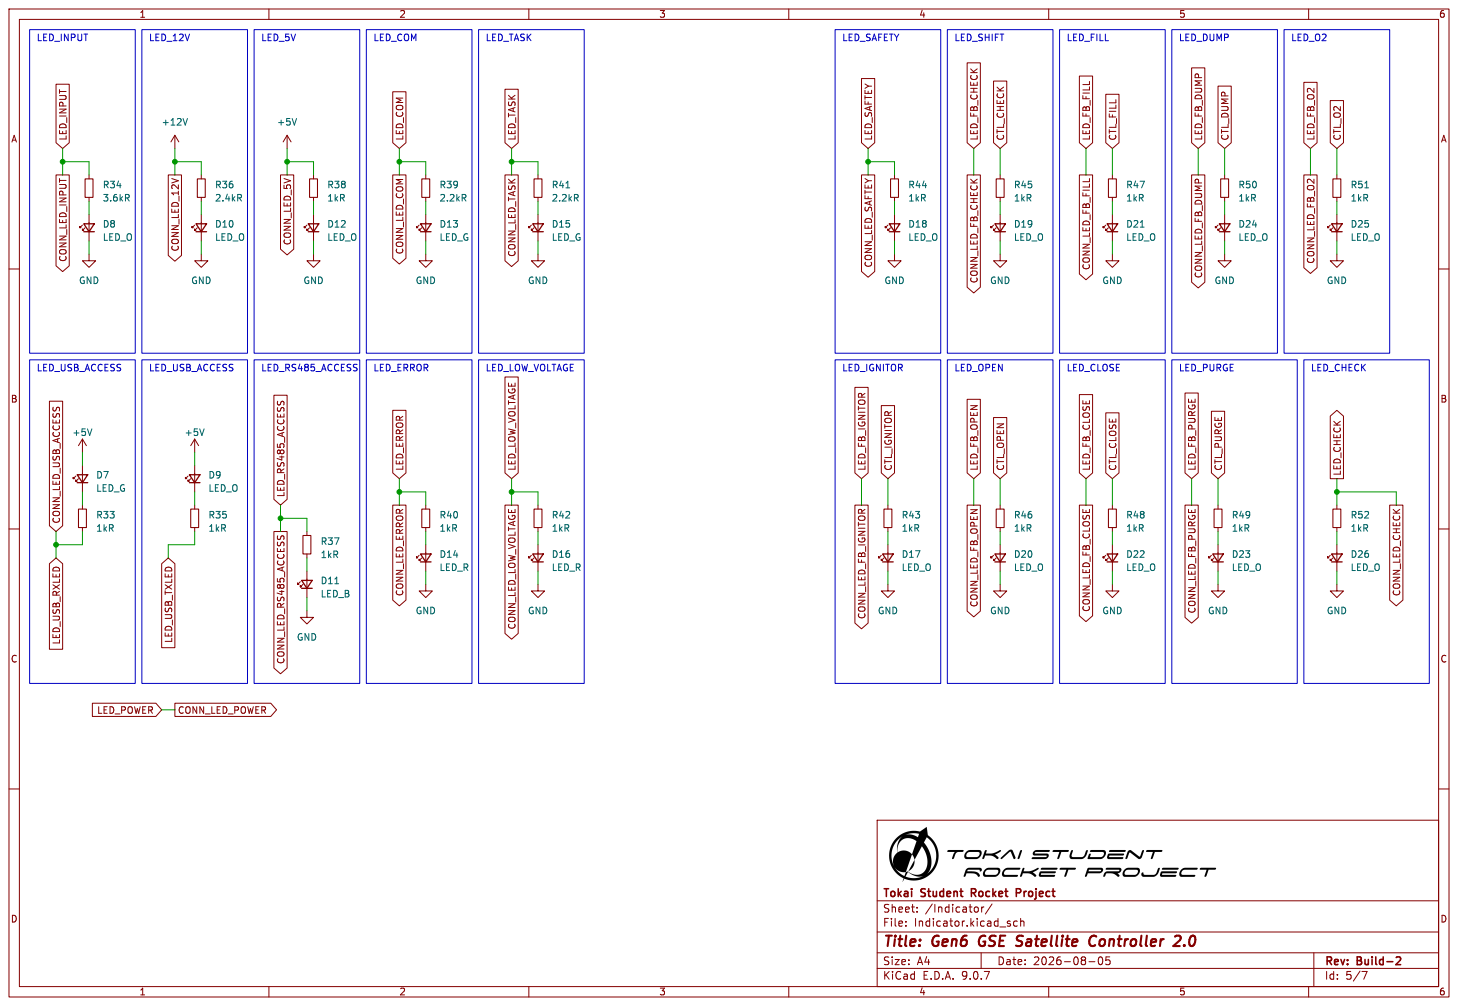
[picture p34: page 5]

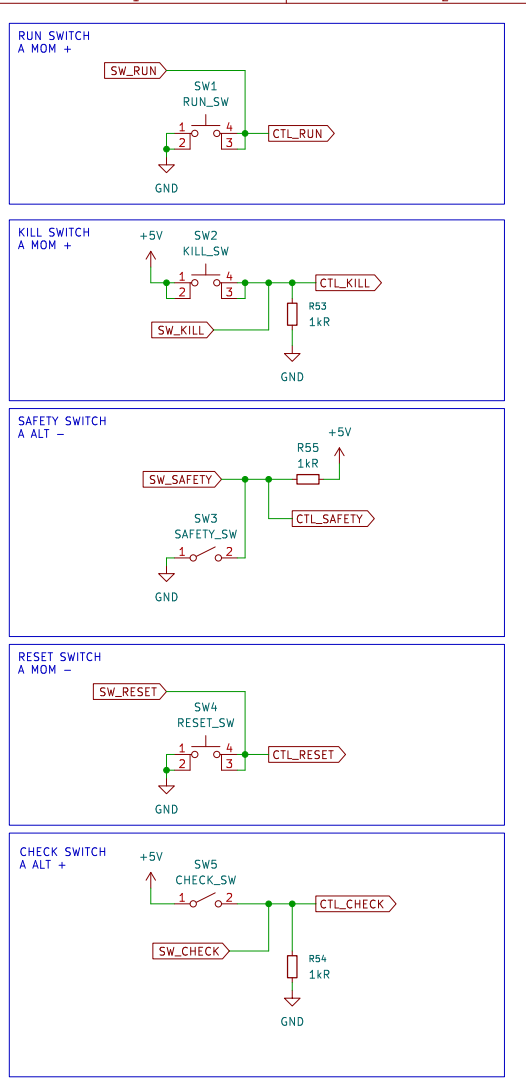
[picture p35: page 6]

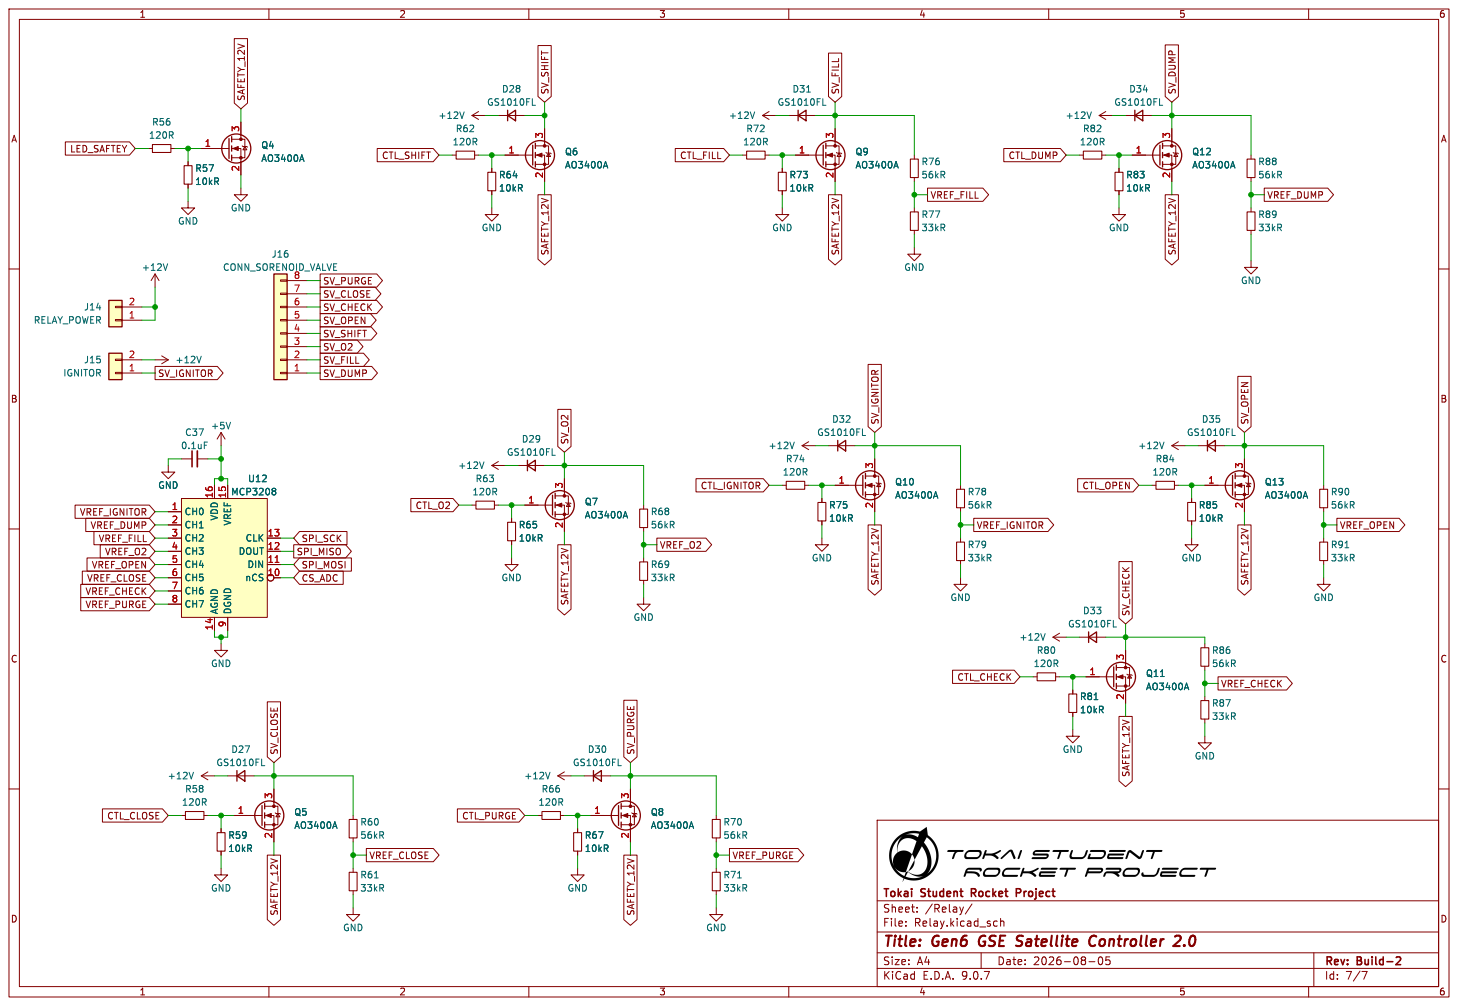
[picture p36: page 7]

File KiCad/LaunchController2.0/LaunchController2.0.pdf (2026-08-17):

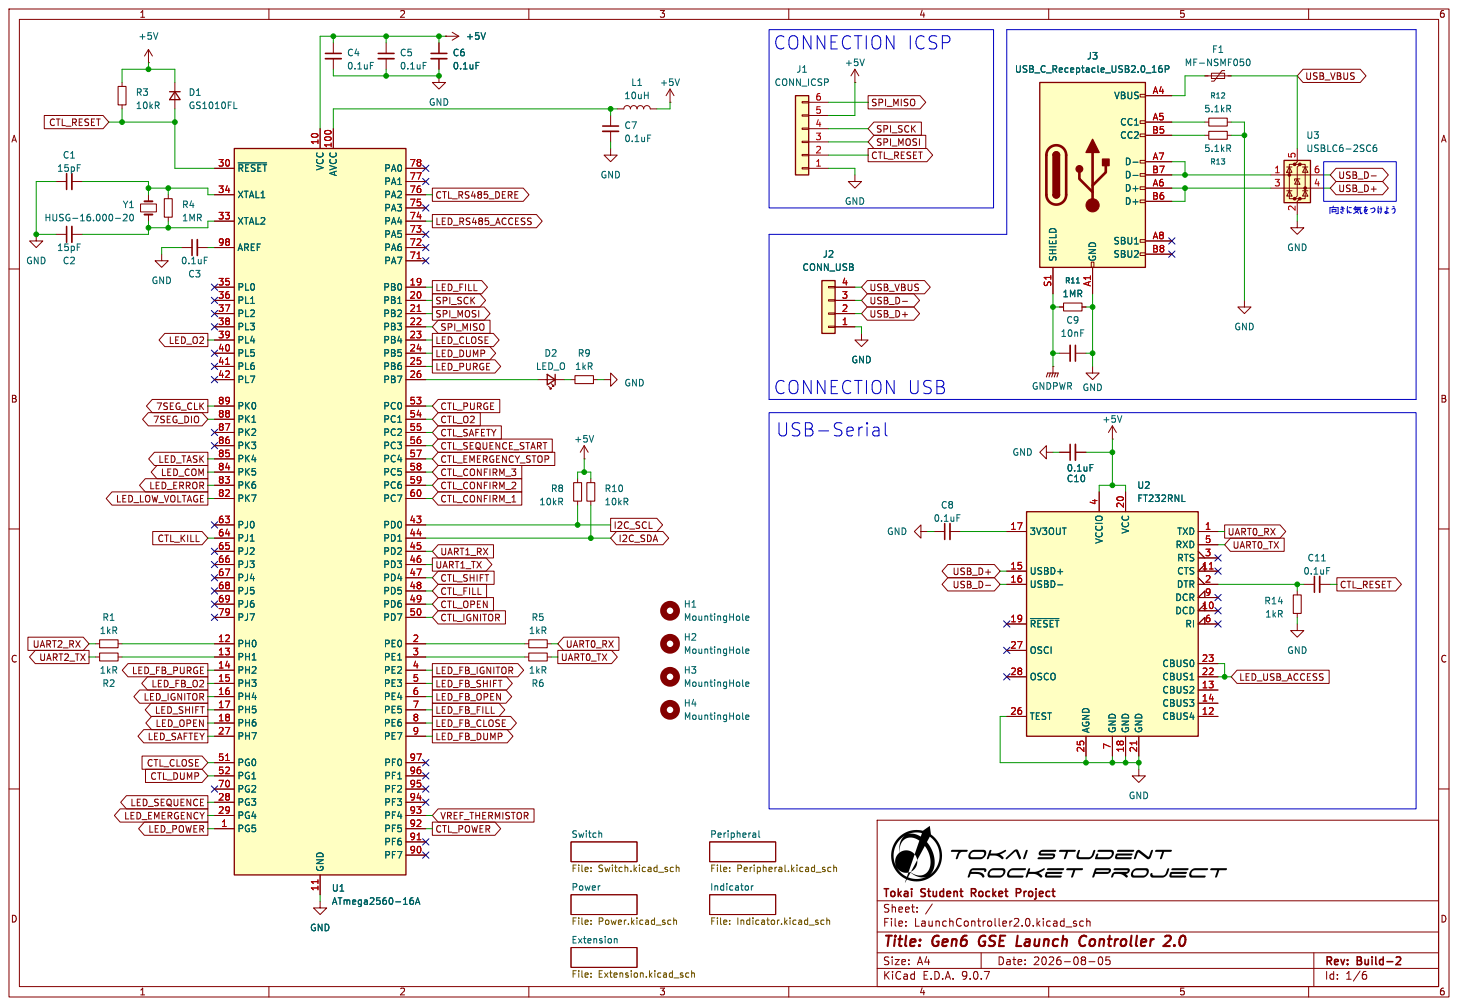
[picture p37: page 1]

7 VCC 20 GND 18 GND 21 TXD 1 RXD 5 RTS 3 CTS 11 DTR 2 DCR 9 DCD 10 RI 6 CBUS0 23 CBUS1 22 CBUS2 13 CBUS3 14 CBUS4 12 C10

7 VCC 20 GND 18 GND 21 TXD 1 RXD 5 RTS 3 CTS 11 DTR 2 DCR 9 DCD 10 RI 6 CBUS0 23 CBUS1 22 CBUS2 13 CBUS3 14 CBUS4 12 U2 FT232RNL

Id: 1/6 Title: Gen6 GSE Launch Controller 2.0

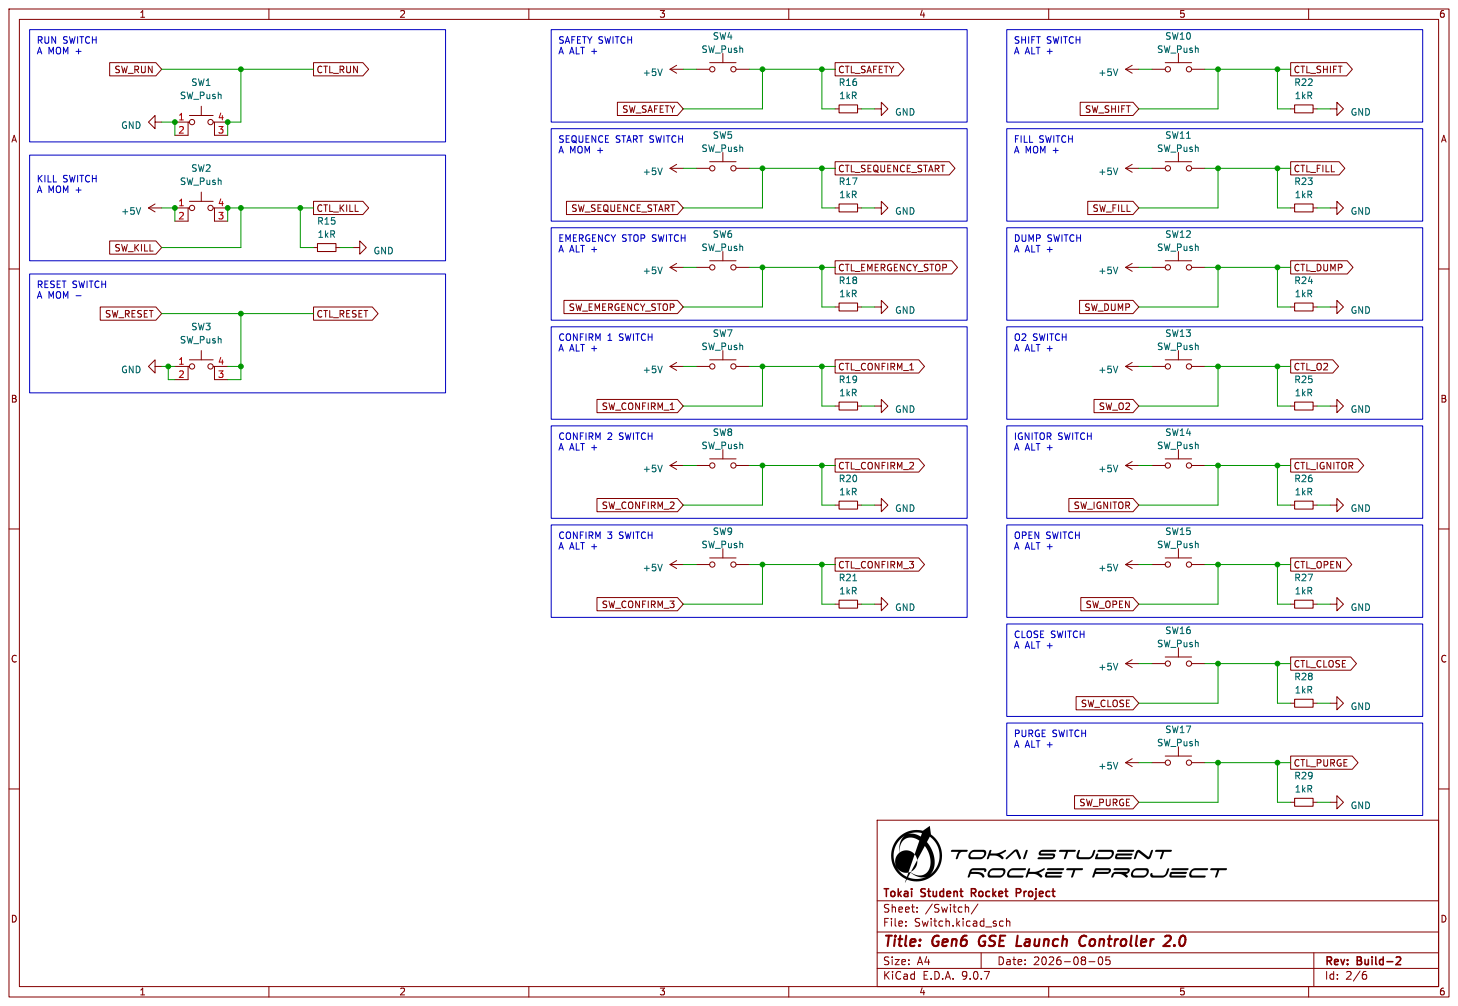
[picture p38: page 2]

A ALT + EMERGENCY STOP SWITCH

A ALT + SEQUENCE START SWITCH

Id: 2/6 Title: Gen6 GSE Launch Controller 2.0

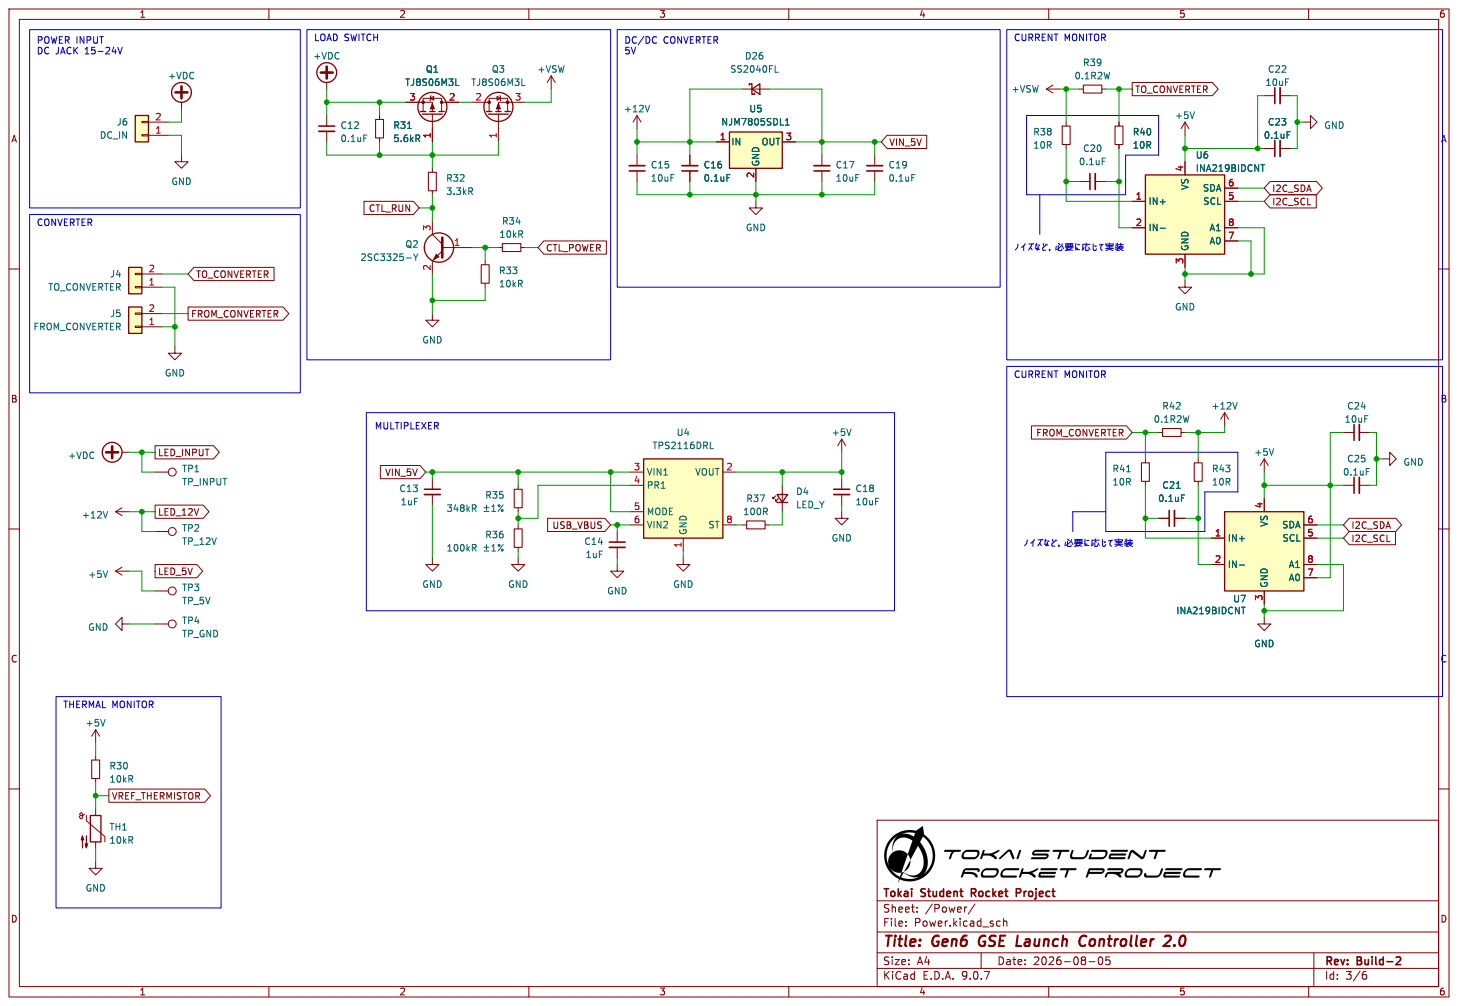
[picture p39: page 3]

Id: 3/6 Title: Gen6 GSE Launch Controller 2.0

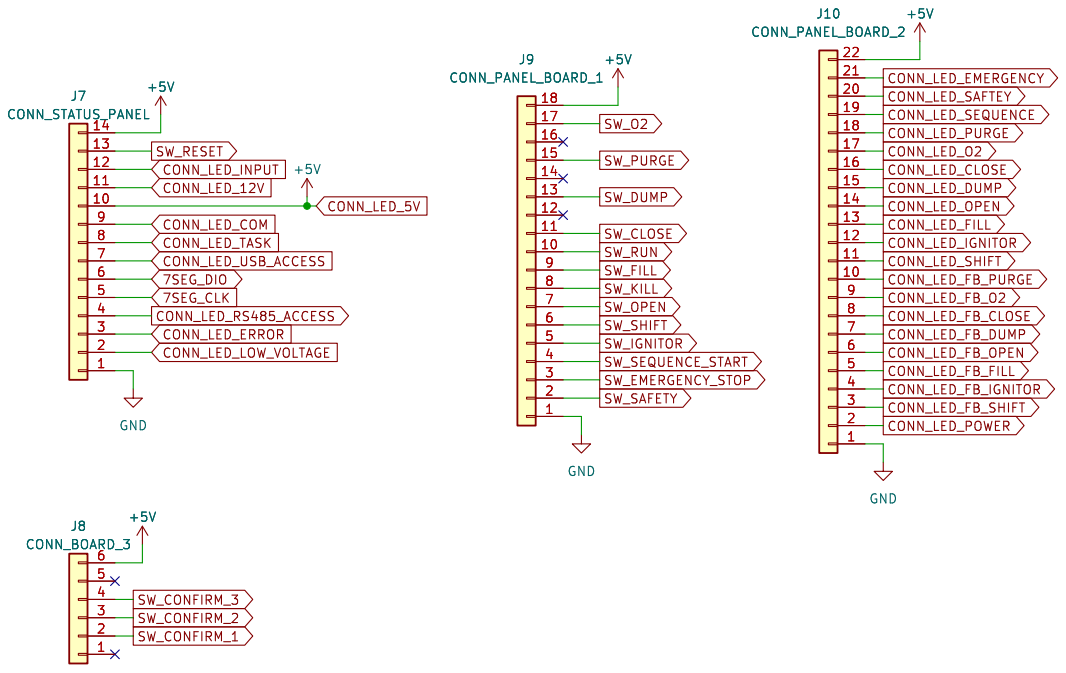
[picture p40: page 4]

Id: 4/6 Title: Gen6 GSE Launch Controller 2.0

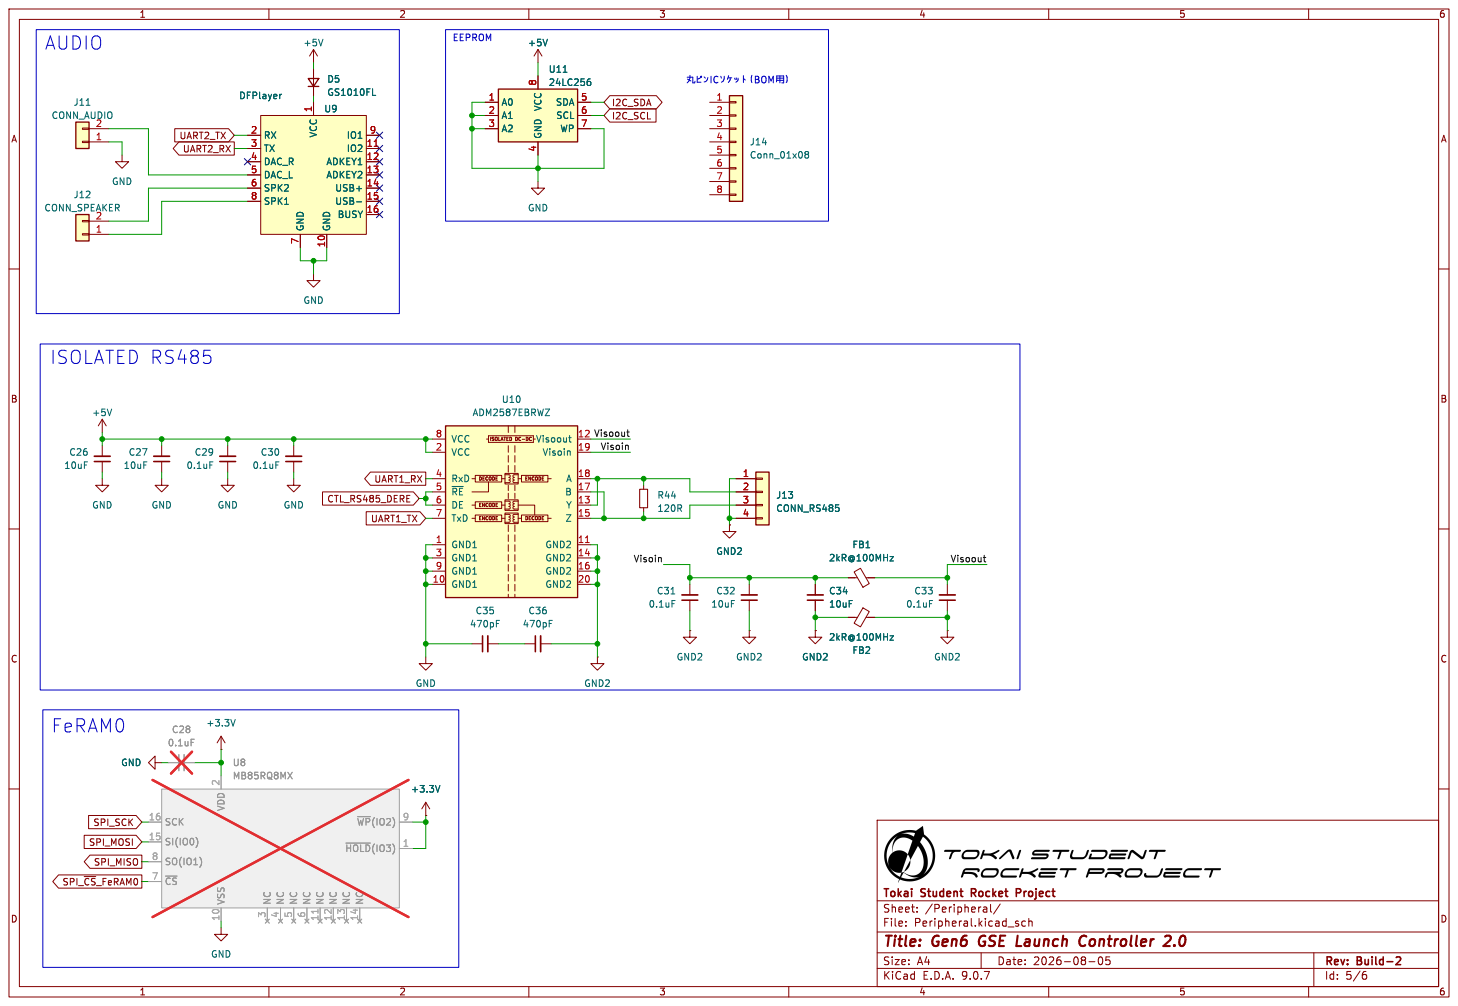
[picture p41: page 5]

Id: 5/6 Title: Gen6 GSE Launch Controller 2.0


Id: 6/6 Title: Gen6 GSE Launch Controller 2.0

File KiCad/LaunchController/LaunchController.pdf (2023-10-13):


þÿ0Õ0¡0¤0ë: Peripheral.kicad_sch Power þÿ0Õ0¡0¤0ë: Power.kicad_sch Switch


POWER INPUT DC JACK 15-24V



4 SDA 5 SCL 6 WP 7 VCC



SHIFT SWITCH A ALT + FILL SWITCH A MOM + DUMP SWITCH A ALT + RESET SWITCH A MOM - CONFIRM 1 SWITCH A ALT + CONFIRM 2 SWITCH A ALT +

Id: 6/6 Title: File: Switch.kicad_sch Sheet: /Switch/ +5V

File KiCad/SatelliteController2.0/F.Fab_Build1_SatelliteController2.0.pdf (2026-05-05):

Satellite Controller 2.; USB +; 2 USB- k"J

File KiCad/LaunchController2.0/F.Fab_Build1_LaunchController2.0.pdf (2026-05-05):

IOR%T; USB + c USB-41"E*T















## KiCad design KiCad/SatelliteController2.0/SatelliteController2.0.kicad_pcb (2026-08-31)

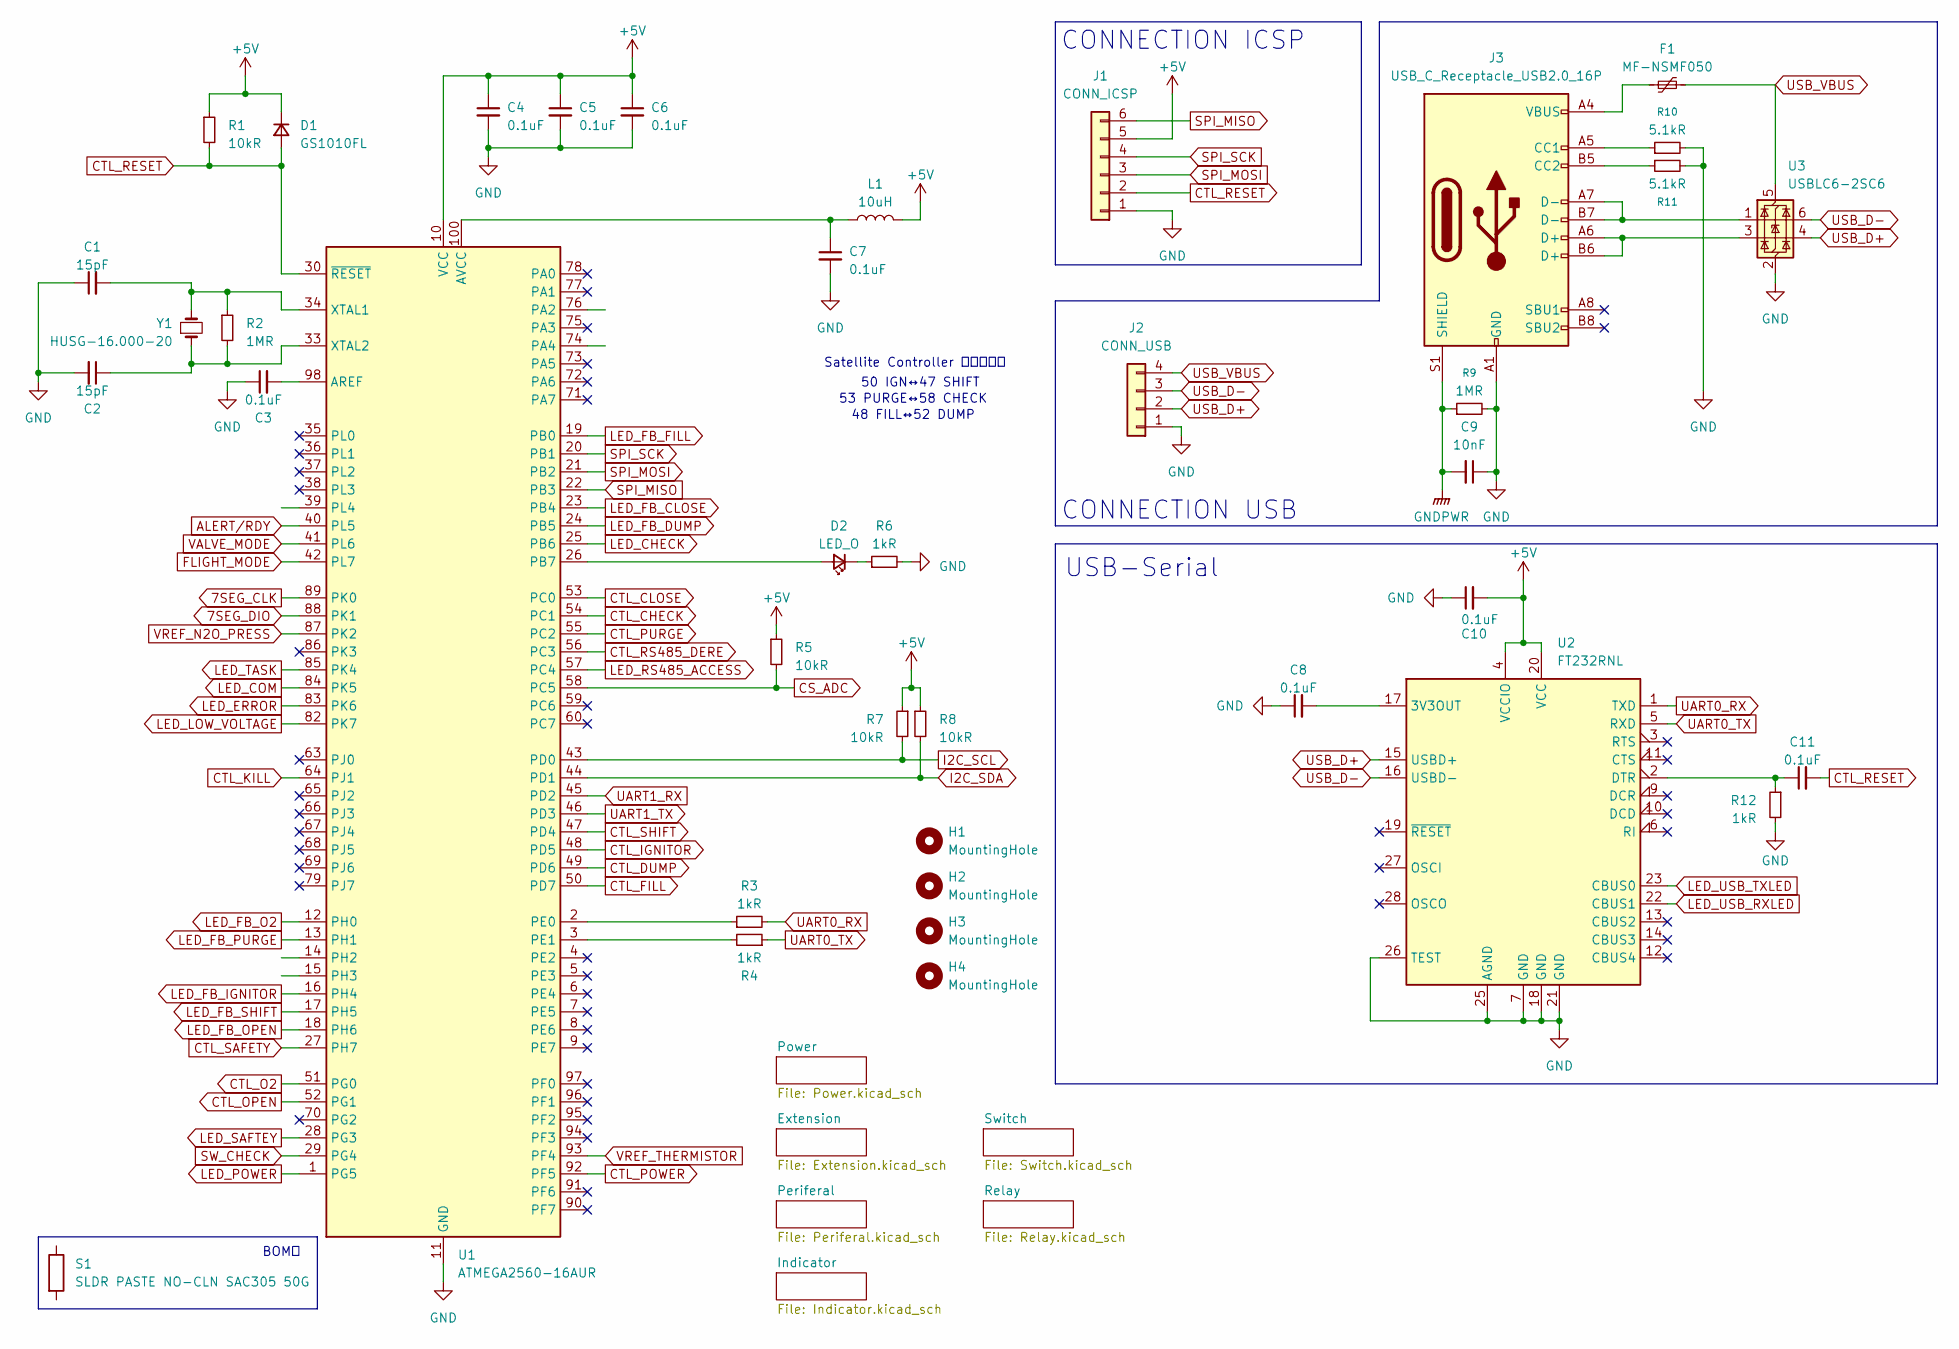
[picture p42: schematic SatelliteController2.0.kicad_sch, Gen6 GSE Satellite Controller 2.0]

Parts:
C1, C2: 15pF; C_0603_1608Metric_Pad1.08x0.95mm_HandSolder
C3, C4, C5, C6, C7, C8, C10, C11: 0.1uF; C_0603_1608Metric_Pad1.08x0.95mm_HandSolder
C9: 10nF; C_0805_2012Metric_Pad1.18x1.45mm_HandSolder; Digikey_PN 490-GCM21B5C2E103FX0ALCT-ND
D1: GS1010FL; D_SOD-123F
D2: LED_O; LED_0603_1608Metric_Pad1.05x0.95mm_HandSolder; Digikey_PN SML-D15DWT86CCT-ND
F1: MF-NSMF050; Fuse_1206_3216Metric_Pad1.42x1.75mm_HandSolder
H1, H2, H3, H4: MountingHole; MountingHole_4.3mm_M4_Pad_Via
J1: CONN_ICSP; PinHeader_1x06_P2.54mm_Vertical
J2: CONN_USB; TerminalBlock_WAGO_2601-3104_1x04_P3.50mm_Vertical; Digikey_PN 2946-2601-3104-ND
J3: USB_C_Receptacle_USB2.0_16P; USB_C_Receptacle_GCT_USB4105-xx-A_16P_TopMnt_Horizontal
L1: 10uH; L_1210_3225Metric_Pad1.42x2.65mm_HandSolder
R1, R5, R7, R8: 10kR; R_0603_1608Metric_Pad0.98x0.95mm_HandSolder; Digikey_PN 2019-RK73H1JTTD1002FCT-ND
R2: 1MR; R_0603_1608Metric_Pad0.98x0.95mm_HandSolder; Digikey_PN 2019-RK73H2BTTD1004FCT-ND
R3, R4, R6, R12: 1kR; R_0603_1608Metric_Pad0.98x0.95mm_HandSolder; Digikey_PN 2019-RK73H1JTTD1001FCT-ND
R9: 1MR; R_1206_3216Metric_Pad1.30x1.75mm_HandSolder; Digikey_PN 2019-RK73H2BTTD1004FCT-ND
R10, R11: 5.1kR; R_0603_1608Metric_Pad0.98x0.95mm_HandSolder; Digikey_PN 2019-RK73H1JTTD5101FCT-ND
S1: SLDR PASTE NO-CLN SAC305 50G; Digikey_PN SMD291SNL50T3-ND
U1: ATMEGA2560-16AUR; TQFP-100_14x14mm_P0.5mm
U2: FT232RNL; SSOP-28_5.3x10.2mm_P0.65mm
U3: USBLC6-2SC6; SOT-23-6; Digikey_PN 497-5235-1-ND
Y1: HUSG-16.000-20; Crystal_HC49-4H_Vertical

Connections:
7SEG_CLK: U1.89 (PK0); also elsewhere on the board
7SEG_DIO: U1.88 (PK1); also elsewhere on the board
ALERT/RDY: U1.40 (PL5); also elsewhere on the board
CONN_LED_5V: C4.1, C5.1, C6.1, C10.2, D1.1 (K), J1.5, L1.2, R1.1, R5.1, R7.1, R8.1, U1.10 (VCC), U1.31 (VCC), U1.61 (VCC), U1.80 (VCC), U2.4 (VCCIO), U2.20 (VCC); also elsewhere on the board
CONN_LED_CHECK: U1.25 (PB6); also elsewhere on the board
CONN_LED_COM: U1.84 (PK5); also elsewhere on the board
CONN_LED_ERROR: U1.83 (PK6); also elsewhere on the board
CONN_LED_LOW_VOLTAGE: U1.82 (PK7); also elsewhere on the board
CONN_LED_RS485_ACCESS: U1.57 (PC4); also elsewhere on the board
CONN_LED_SAFTEY: U1.28 (PG3); also elsewhere on the board
CONN_LED_TASK: U1.85 (PK4); also elsewhere on the board
CONN_LED_USB_ACCESS: U2.22 (CBUS1); also elsewhere on the board
CS_ADC: R5.2, U1.58 (PC5); also elsewhere on the board
CTL_CHECK: U1.29 (PG4), U1.54 (PC1); also elsewhere on the board
CTL_CLOSE: U1.53 (PC0); also elsewhere on the board
CTL_DUMP: U1.49 (PD6); also elsewhere on the board
CTL_FILL: U1.50 (PD7); also elsewhere on the board
CTL_IGNITOR: U1.48 (PD5); also elsewhere on the board
CTL_KILL: U1.64 (PJ1); also elsewhere on the board
CTL_O2: U1.51 (PG0); also elsewhere on the board
CTL_OPEN: U1.52 (PG1); also elsewhere on the board
CTL_POWER: U1.92 (PF5); also elsewhere on the board
CTL_PURGE: U1.55 (PC2); also elsewhere on the board
CTL_RESET: C11.2, D1.2 (A), J1.2, R1.2, U1.30 (~RESET); also elsewhere on the board
CTL_RS485_DERE: U1.56 (PC3); also elsewhere on the board
CTL_SAFETY: U1.27 (PH7); also elsewhere on the board
CTL_SHIFT: U1.47 (PD4); also elsewhere on the board
FLIGHT_MODE: U1.42 (PL7); also elsewhere on the board
GND: C1.1, C2.2, C3.1, C4.2, C5.2, C6.2, C7.2, C8.1, C9.1, C10.1, J1.1, J2.1, J3.A1 (GND), J3.A12 (GND), J3.B1 (GND), J3.B12 (GND), R6.2, R9.2, R10.2, R11.2, R12.2, U1.11 (GND), U1.32 (GND), U1.62 (GND), U1.81 (GND), U1.99 (GND), U2.7 (GND), U2.18 (GND), U2.21 (GND), U2.25 (AGND), U2.26 (TEST), U3.2 (GND); also elsewhere on the board
GNDPWR: C9.2, J3.S1 (SHIELD), R9.1
I2C_SCL: R7.2, U1.43 (PD0); also elsewhere on the board
I2C_SDA: R8.2, U1.44 (PD1); also elsewhere on the board
LED_FB_SHIFT: U1.17 (PH5)
LED_USB_TXLED: U2.23 (CBUS0); also elsewhere on the board
unnamed: D2.2 (A), U1.26 (PB7)
unnamed: D2.1 (K), R6.1
unnamed: F1.1, J3.A4 (VBUS), J3.A9 (VBUS), J3.B4 (VBUS), J3.B9 (VBUS)
unnamed: J3.A5 (CC1), R10.1
unnamed: J3.B5 (CC2), R11.1
unnamed: J3.A6 (D+), J3.B6 (D+), U3.3 (I/O2)
unnamed: J3.A7 (D-), J3.B7 (D-), U3.1 (I/O1)
unnamed: C3.2, U1.98 (AREF)
unnamed: C7.1, L1.1, U1.100 (AVCC)
unnamed: R3.1, U1.2 (PE0)
unnamed: R4.2, U1.3 (PE1)
unnamed: C1.2, R2.1, U1.34 (XTAL1), Y1.2
unnamed: C2.1, R2.2, U1.33 (XTAL2), Y1.1
unnamed: C8.2, U2.17 (3V3OUT)
unnamed: C11.1, R12.1, U2.2 (DTR)
SPI_MISO: J1.6, U1.22 (PB3); also elsewhere on the board
SPI_MOSI: J1.3, U1.21 (PB2); also elsewhere on the board
SPI_SCK: J1.4, U1.20 (PB1); also elsewhere on the board
UART0_RX: R3.2, U2.1 (TXD)
UART0_TX: R4.1, U2.5 (RXD)
UART1_RX: U1.45 (PD2); also elsewhere on the board
UART1_TX: U1.46 (PD3); also elsewhere on the board
USB_D+: J2.2, U2.15 (USBD+), U3.4 (I/O2)
USB_D-: J2.3, U2.16 (USBD-), U3.6 (I/O1)
USB_VBUS: F1.2, J2.4, U3.5 (VBUS); also elsewhere on the board
VALVE_MODE: U1.41 (PL6); also elsewhere on the board
VREF_N2O_PRESS: U1.87 (PK2)
VREF_THERMISTOR: U1.93 (PF4); also elsewhere on the board

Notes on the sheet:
53 PURGE↔58 CHECK
48 FILL↔52 DUMP
Satellite Controller との変更点
USB-Serial
50 IGN↔47 SHIFT
BOM用
CONNECTION ICSP
CONNECTION USB

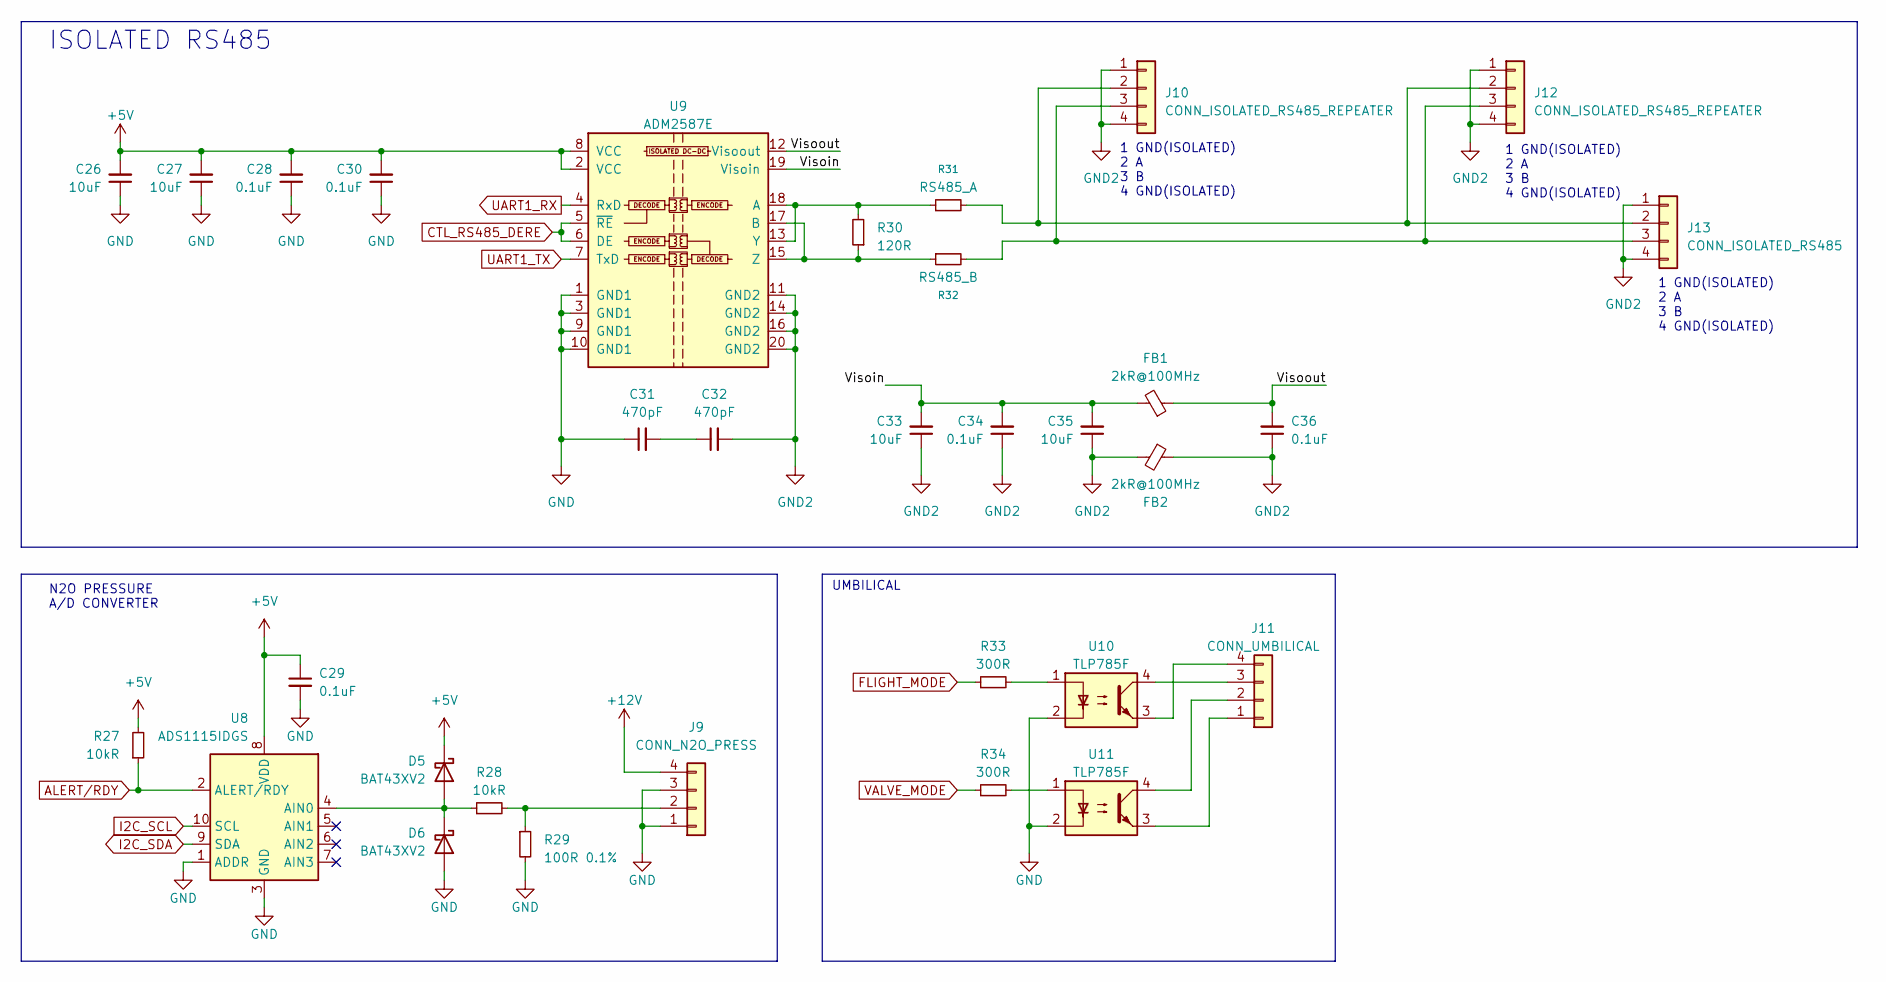
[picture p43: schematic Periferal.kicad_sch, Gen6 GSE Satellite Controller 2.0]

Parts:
C26, C27, C33, C35: 10uF; C_0805_2012Metric_Pad1.18x1.45mm_HandSolder
C28, C29, C30, C34, C36: 0.1uF; C_0603_1608Metric_Pad1.08x0.95mm_HandSolder
C31, C32: 470pF; C_1206_3216Metric_Pad1.33x1.80mm_HandSolder; Digikey_PN 445-5785-1-ND
D5, D6: BAT43XV2; D_SOD-523
FB1, FB2: 2kR@100MHz; L_0603_1608Metric_Pad1.05x0.95mm_HandSolder; Digikey_PN 445-MMZ1608S202ATA00CT-ND
J9: CONN_N2O_PRESS; TerminalBlock_WAGO_2601-3104_1x04_P3.50mm_Vertical; Digikey_PN 2946-2601-3104-ND
J10, J12: CONN_ISOLATED_RS485_REPEATER; TerminalBlock_WAGO_2601-3104_1x04_P3.50mm_Vertical; Digikey_PN 2946-2601-3104-ND
J11: CONN_UMBILICAL; TerminalBlock_WAGO_2601-3104_1x04_P3.50mm_Vertical; Digikey_PN 2946-2601-3104-ND
J13: CONN_ISOLATED_RS485; TerminalBlock_WAGO_2601-3104_1x04_P3.50mm_Vertical; Digikey_PN 2946-2601-3104-ND
R27, R28: 10kR; R_0603_1608Metric_Pad0.98x0.95mm_HandSolder; Digikey_PN 2019-RK73H1JTTD1002FCT-ND
R29: 100R 0.1%; R_0805_2012Metric_Pad1.20x1.40mm_HandSolder
R30: 120R; R_0805_2012Metric_Pad1.20x1.40mm_HandSolder; Digikey_PN 2019-RK73H2ATTD1200FCT-ND
R31: RS485_A; R_0805_2012Metric_Pad1.20x1.40mm_HandSolder
R32: RS485_B; R_0805_2012Metric_Pad1.20x1.40mm_HandSolder
R33, R34: 300R; R_0603_1608Metric_Pad0.98x0.95mm_HandSolder; Digikey_PN 2019-RK73H1JTTD3000FCT-ND
U8: ADS1115IDGS; TSSOP-10_3x3mm_P0.5mm; Digikey_PN 296-38849-1-ND
U9: ADM2587E; SOIC-20W_7.5x12.8mm_P1.27mm
U10, U11: TLP785F; DIP-4_W10.16mm

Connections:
/Periferal/Visoin: C33.2, C34.2, C35.2, FB1.2, U9.19 (Visoin)
/Periferal/Visoout: C36.2, FB1.1, U9.12 (Visoout)
ALERT/RDY: R27.1, U8.2 (ALERT/RDY); also elsewhere on the board
CONN_LED_5V: C26.2, C27.2, C28.2, C29.1, C30.2, D5.1 (K), R27.2, U8.8 (VDD), U9.2 (VCC), U9.8 (VCC); also elsewhere on the board
CONN_LED_12V: J9.4; also elsewhere on the board
CTL_RS485_DERE: U9.5 (~RE), U9.6 (DE); also elsewhere on the board
FLIGHT_MODE: R33.1; also elsewhere on the board
GND: C26.1, C27.1, C28.1, C29.2, C30.1, C31.1, D6.2 (A), J9.1, J9.3, R29.2, U8.1 (ADDR), U8.3 (GND), U9.1 (GND1), U9.3 (GND1), U9.9 (GND1), U9.10 (GND1), U10.2, U11.2; also elsewhere on the board
GND2: C32.2, C33.1, C34.1, C35.1, C36.1, FB2.1, FB2.2, J10.1, J10.4, J12.1, J12.4, J13.1, J13.4, U9.11 (GND2), U9.14 (GND2), U9.16 (GND2), U9.20 (GND2)
I2C_SCL: U8.10 (SCL); also elsewhere on the board
I2C_SDA: U8.9 (SDA); also elsewhere on the board
unnamed: C31.2, C32.1
unnamed: D5.2 (A), D6.1 (K), R28.1, U8.4 (AIN0)
unnamed: J9.2, R28.2, R29.1
unnamed: J10.2, J12.2, J13.2, R31.2
unnamed: J10.3, J12.3, J13.3, R32.2
unnamed: J11.1, U11.3
unnamed: J11.2, U11.4
unnamed: J11.3, U10.4
unnamed: J11.4, U10.3
unnamed: R33.2, U10.1
unnamed: R34.2, U11.1
unnamed: R30.2, R31.1, U9.13 (Y), U9.18 (A)
unnamed: R30.1, R32.1, U9.15 (Z), U9.17 (B)
UART1_RX: U9.4 (RxD); also elsewhere on the board
UART1_TX: U9.7 (TxD); also elsewhere on the board
VALVE_MODE: R34.1; also elsewhere on the board

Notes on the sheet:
1 GND(ISOLATED) 2 A 3 B 4 GND(ISOLATED)
UMBILICAL
N2O PRESSURE A/D CONVERTER
ISOLATED RS485

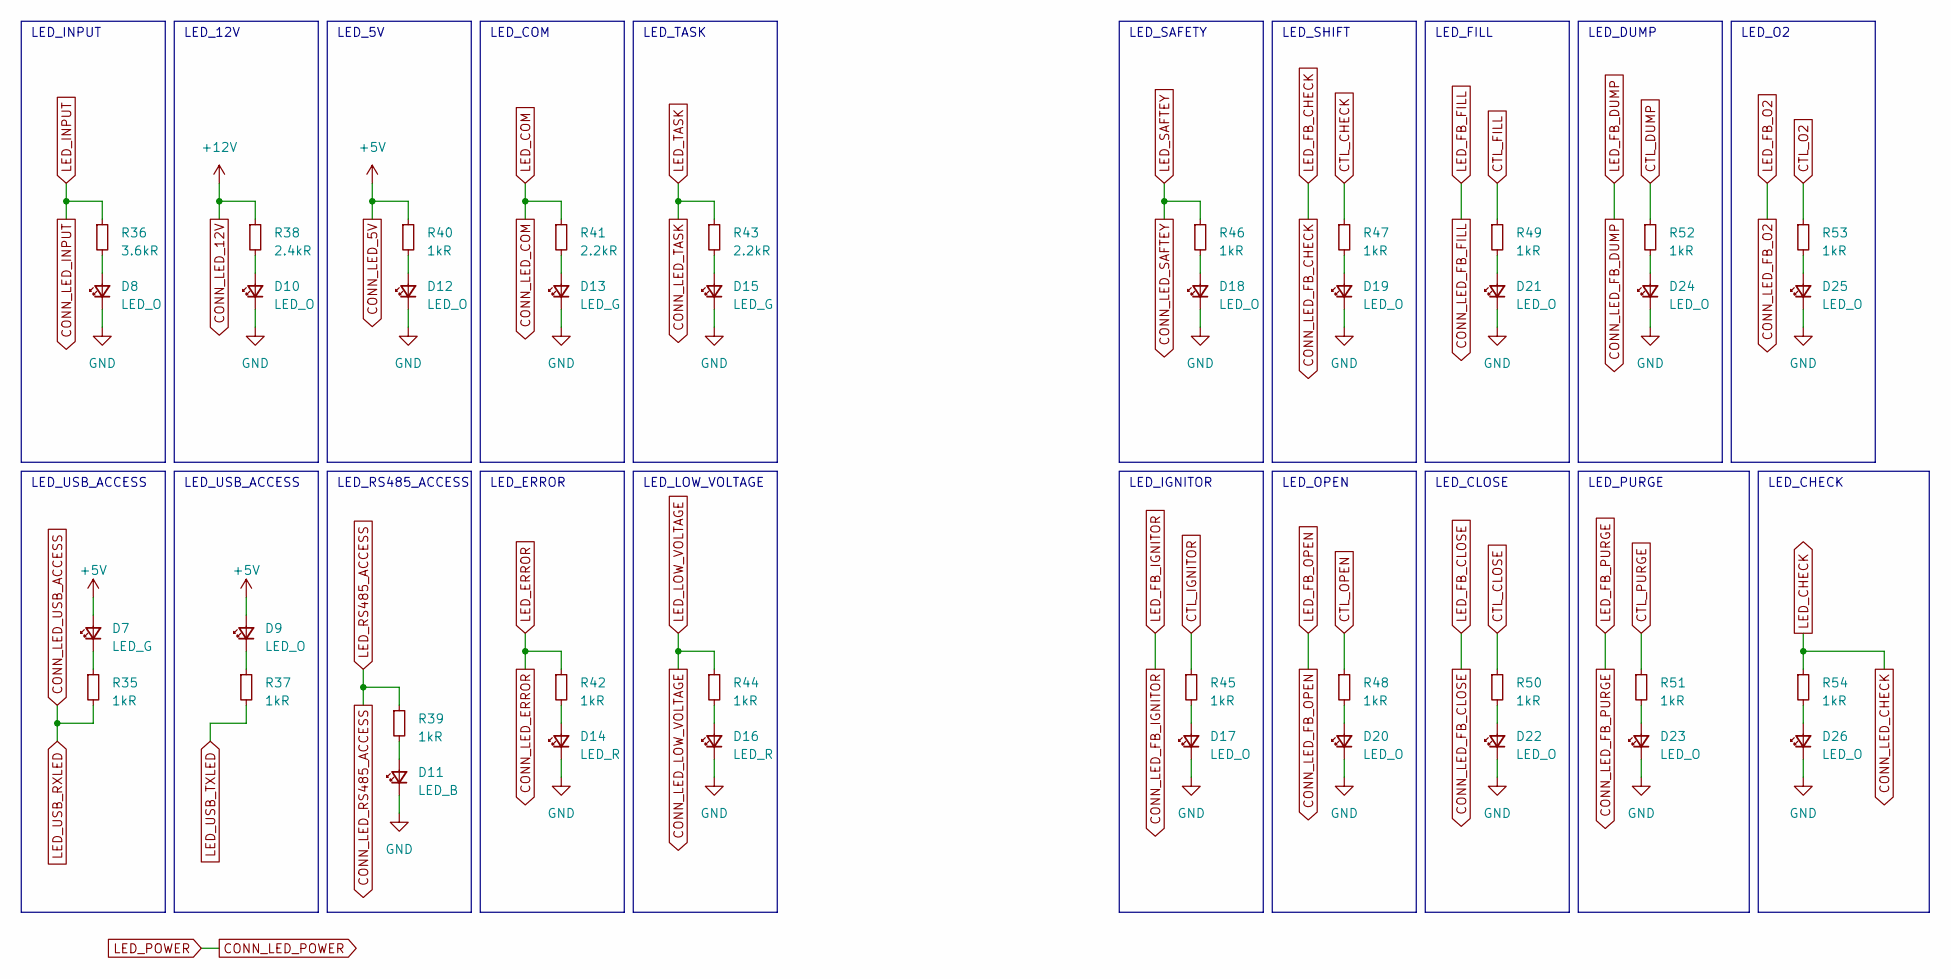
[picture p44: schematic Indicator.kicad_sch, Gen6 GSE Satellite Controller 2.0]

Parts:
D7, D13, D15: LED_G; LED_0603_1608Metric_Pad1.05x0.95mm_HandSolder; Digikey_PN SML-D12P8WT86CCT-ND
D8, D9, D10, D12, D17, D18, D19, D20, D21, D22, D23, D24, D25, D26: LED_O; LED_0603_1608Metric_Pad1.05x0.95mm_HandSolder; Digikey_PN SML-D15DWT86CCT-ND
D11: LED_B; LED_0603_1608Metric_Pad1.05x0.95mm_HandSolder; Digikey_PN SMLD12BN1WT86CT-ND
D14, D16: LED_R; LED_0603_1608Metric_Pad1.05x0.95mm_HandSolder; Digikey_PN SML-D12U8WT86CCT-ND
R35, R37, R39, R40, R42, R44, R45, R46, R47, R48, R49, R50, R51, R52, R53, R54: 1kR; R_0603_1608Metric_Pad0.98x0.95mm_HandSolder; Digikey_PN 2019-RK73H1JTTD1001FCT-ND
R36: 3.6kR; R_0603_1608Metric_Pad0.98x0.95mm_HandSolder; Digikey_PN 2019-RK73H1JTTD3601FCT-ND
R38: 2.4kR; R_0603_1608Metric_Pad0.98x0.95mm_HandSolder; Digikey_PN 2019-RK73H1JTTD2401FCT-ND
R41, R43: 2.2kR; R_0603_1608Metric_Pad0.98x0.95mm_HandSolder; Digikey_PN 2019-RK73H1JTTD2201FCT-ND

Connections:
CONN_LED_5V: D7.2 (A), D9.2 (A), R40.1; also elsewhere on the board
CONN_LED_12V: R38.1; also elsewhere on the board
CONN_LED_CHECK: R54.1; also elsewhere on the board
CONN_LED_COM: R41.1; also elsewhere on the board
CONN_LED_ERROR: R42.1; also elsewhere on the board
CONN_LED_INPUT: R36.1; also elsewhere on the board
CONN_LED_LOW_VOLTAGE: R44.1; also elsewhere on the board
CONN_LED_RS485_ACCESS: R39.1; also elsewhere on the board
CONN_LED_SAFTEY: R46.1; also elsewhere on the board
CONN_LED_TASK: R43.1; also elsewhere on the board
CONN_LED_USB_ACCESS: R35.2; also elsewhere on the board
CTL_CHECK: R47.1; also elsewhere on the board
CTL_CLOSE: R50.1; also elsewhere on the board
CTL_DUMP: R52.1; also elsewhere on the board
CTL_FILL: R49.1; also elsewhere on the board
CTL_IGNITOR: R45.1; also elsewhere on the board
CTL_O2: R53.1; also elsewhere on the board
CTL_OPEN: R48.1; also elsewhere on the board
CTL_PURGE: R51.1; also elsewhere on the board
GND: D8.1 (K), D10.1 (K), D11.1 (K), D12.1 (K), D13.1 (K), D14.1 (K), D15.1 (K), D16.1 (K), D17.1 (K), D18.1 (K), D19.1 (K), D20.1 (K), D21.1 (K), D22.1 (K), D23.1 (K), D24.1 (K), D25.1 (K), D26.1 (K); also elsewhere on the board
LED_USB_TXLED: R37.2; also elsewhere on the board
unnamed: D7.1 (K), R35.1
unnamed: D8.2 (A), R36.2
unnamed: D9.1 (K), R37.1
unnamed: D10.2 (A), R38.2
unnamed: D11.2 (A), R39.2
unnamed: D12.2 (A), R40.2
unnamed: D13.2 (A), R41.2
unnamed: D14.2 (A), R42.2
unnamed: D15.2 (A), R43.2
unnamed: D16.2 (A), R44.2
unnamed: D17.2 (A), R45.2
unnamed: D18.2 (A), R46.2
unnamed: D19.2 (A), R47.2
unnamed: D20.2 (A), R48.2
unnamed: D21.2 (A), R49.2
unnamed: D22.2 (A), R50.2
unnamed: D23.2 (A), R51.2
unnamed: D24.2 (A), R52.2
unnamed: D25.2 (A), R53.2
unnamed: D26.2 (A), R54.2

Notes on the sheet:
LED_SHIFT
LED_IGNITOR
LED_PURGE
LED_INPUT
LED_RS485_ACCESS
LED_5V
LED_CLOSE
LED_ERROR
LED_DUMP
LED_TASK
LED_SAFETY
LED_LOW_VOLTAGE
LED_USB_ACCESS
LED_O2
LED_OPEN
LED_12V
LED_FILL
LED_CHECK
LED_COM

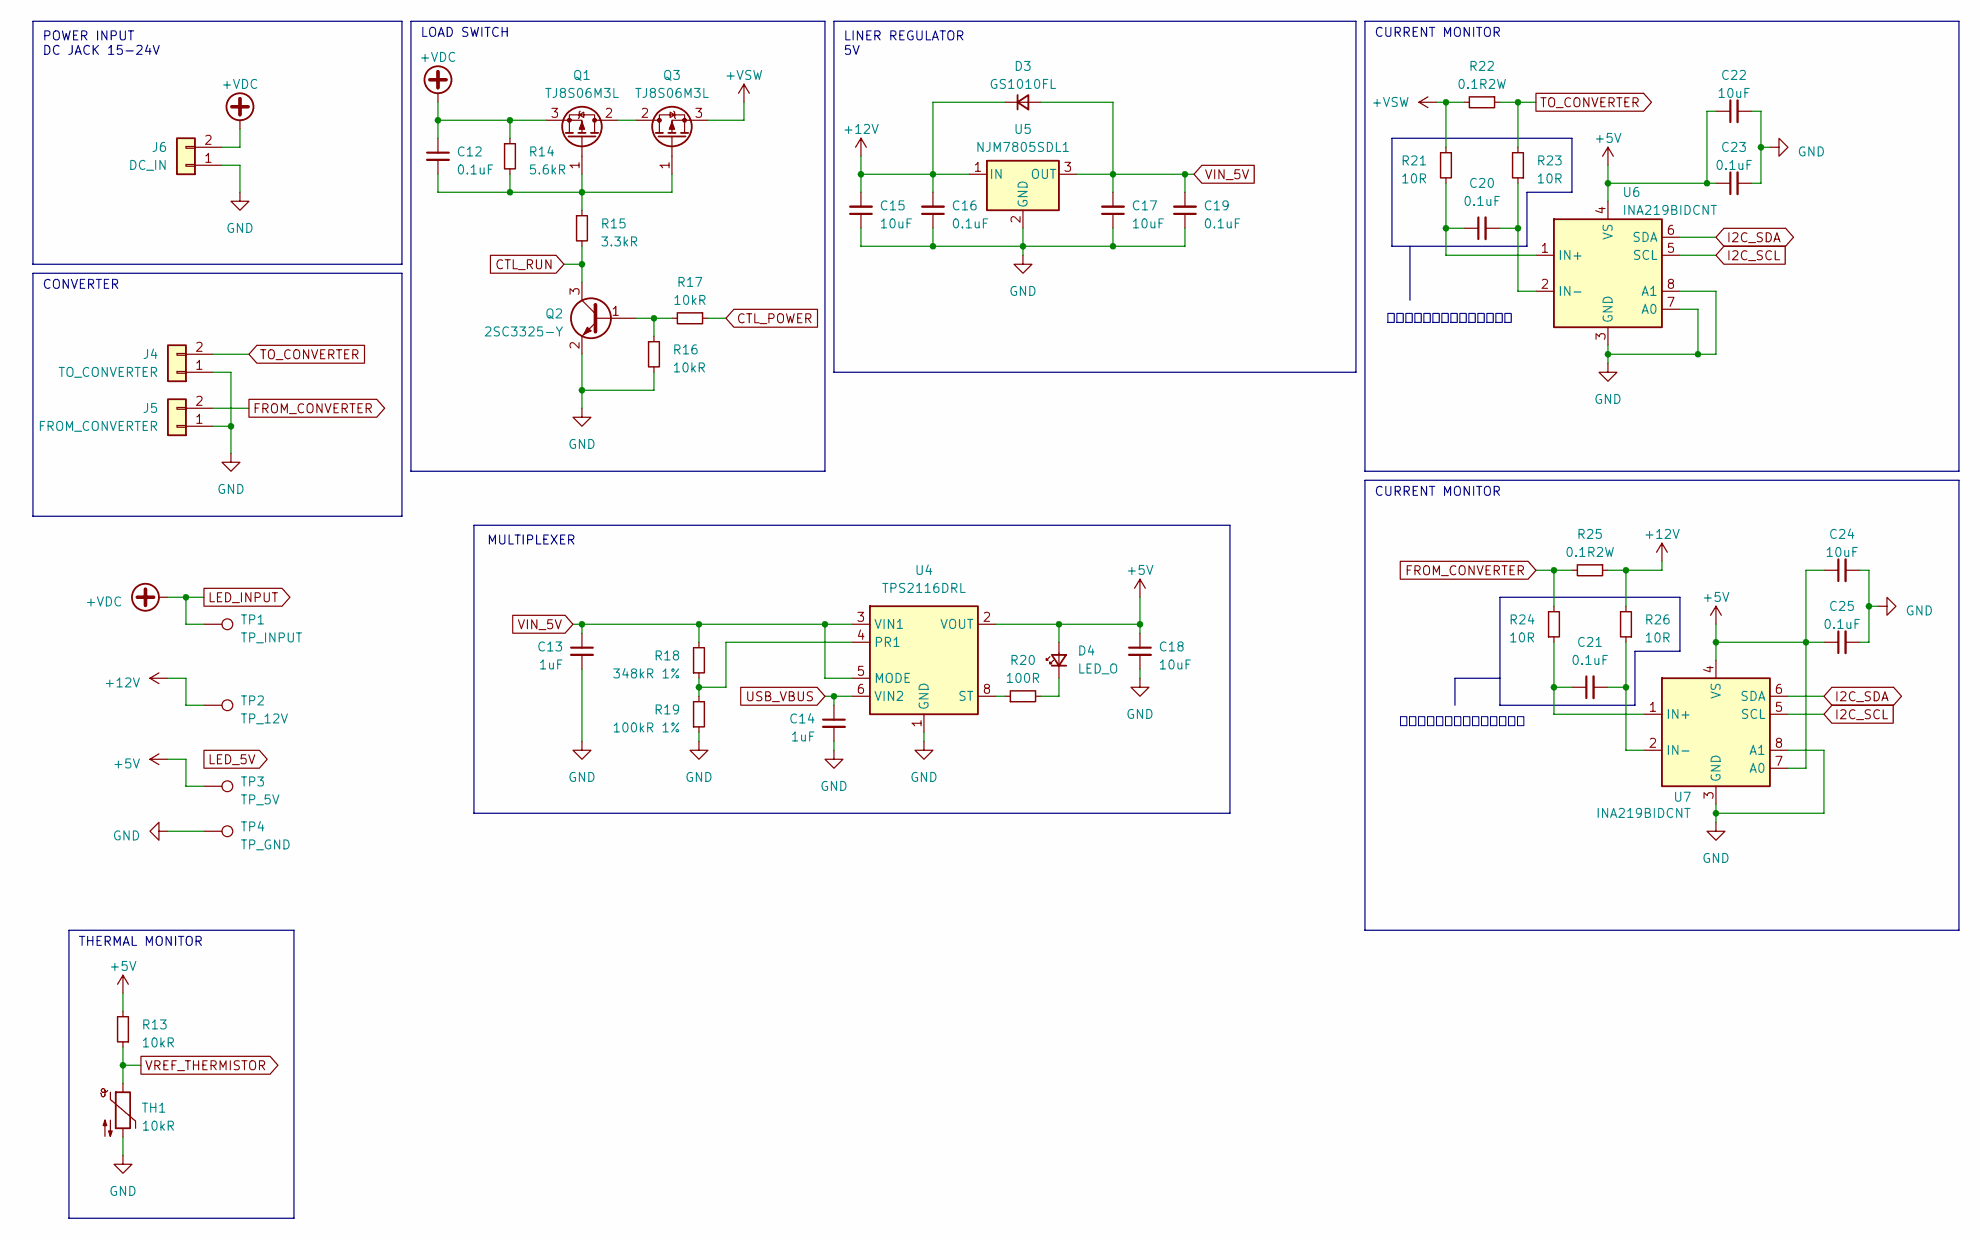
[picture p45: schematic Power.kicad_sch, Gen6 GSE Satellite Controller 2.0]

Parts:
C12, C16, C19, C20, C21, C23, C25: 0.1uF; C_0603_1608Metric_Pad1.08x0.95mm_HandSolder
C13, C14: 1uF; C_0603_1608Metric_Pad1.08x0.95mm_HandSolder
C15, C17: 10uF; C_1206_3216Metric_Pad1.33x1.80mm_HandSolder
C18, C22, C24: 10uF; C_0805_2012Metric_Pad1.18x1.45mm_HandSolder
D3: GS1010FL; D_SOD-123F
D4: LED_O; LED_0603_1608Metric_Pad1.05x0.95mm_HandSolder; Digikey_PN SML-D15DWT86CCT-ND
J4: TO_CONVERTER; TerminalBlock_WAGO_2601-3102_1x02_P3.50mm_Vertical; Digikey_PN 2946-2601-3102-ND
J5: FROM_CONVERTER; TerminalBlock_WAGO_2601-3102_1x02_P3.50mm_Vertical; Digikey_PN 2946-2601-3102-ND
J6: DC_IN; TerminalBlock_WAGO_2601-3102_1x02_P3.50mm_Vertical; Digikey_PN 2946-2601-3102-ND
Q1, Q3: TJ8S06M3L; TO-252-2
Q2: 2SC3325-Y; SC-59_Handsoldering
R13, R16, R17: 10kR; R_0603_1608Metric_Pad0.98x0.95mm_HandSolder; Digikey_PN 2019-RK73H1JTTD1002FCT-ND
R14: 5.6kR; R_0603_1608Metric_Pad0.98x0.95mm_HandSolder; Digikey_PN 2019-RK73H1JTTD5601FCT-ND
R15: 3.3kR; R_0603_1608Metric_Pad0.98x0.95mm_HandSolder; Digikey_PN 2019-RK73H1JTTD3301FCT-ND
R18: 348kR 1%; R_0603_1608Metric_Pad0.98x0.95mm_HandSolder; Digikey_PN 2019-RK73H1JTTD3483FCT-ND
R19: 100kR 1%; R_0603_1608Metric_Pad0.98x0.95mm_HandSolder; Digikey_PN 2019-RK73H1JTTD1003FCT-ND
R20: 100R; R_0603_1608Metric_Pad0.98x0.95mm_HandSolder; Digikey_PN 2019-RK73H1JTTD1000FCT-ND
R21, R23, R24, R26: 10R; R_0603_1608Metric_Pad0.98x0.95mm_HandSolder; Digikey_PN 2019-RK73H1JTTD10R0FCT-ND
R22, R25: 0.1R2W; R_2816_7142Metric_Pad3.20x4.45mm_HandSolder; Digikey_PN CRM2512-FX-R100ELFCT-ND
TH1: 10kR; R_0603_1608Metric_Pad0.98x0.95mm_HandSolder; Digikey_PN 2019-RK73H1JTTD1002FCT-ND
TP1: TP_INPUT; TestPoint_Keystone_5005-5009_Compact
TP2: TP_12V; TestPoint_Keystone_5005-5009_Compact
TP3: TP_5V; TestPoint_Keystone_5005-5009_Compact
TP4: TP_GND; TestPoint_Keystone_5005-5009_Compact
U4: TPS2116DRL; SOT-583-8; Digikey_PN 296-TPS2116DRLRCT-ND
U5: NJM7805SDL1; TO-252-2
U6, U7: INA219BIDCNT; SOT-23-8; Digikey_PN 296-27898-1-ND

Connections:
+VSW: Q3.3 (S), R21.1, R22.2
CONN_LED_5V: C18.1, C22.1, C23.1, C24.1, C25.1, D4.2 (A), R13.2, TP3.1, U4.2 (VOUT), U4.7 (VOUT), U6.4 (VS), U7.4 (VS), U7.7 (A0); also elsewhere on the board
CONN_LED_12V: C15.2, C16.2, D3.1 (K), R25.1, R26.2, TP2.1, U5.1 (IN); also elsewhere on the board
CONN_LED_INPUT: C12.1, J6.2, Q1.3 (S), R14.1, TP1.1; also elsewhere on the board
CTL_POWER: R17.1; also elsewhere on the board
CTL_RUN: Q2.3 (C), R15.2; also elsewhere on the board
FROM_CONVERTER: J5.2, R24.2, R25.2
GND: C13.2, C14.2, C15.1, C16.1, C17.1, C18.2, C19.1, C22.2, C23.2, C24.2, C25.2, J4.1, J5.1, J6.1, Q2.2 (E), R16.2, R19.1, TH1.2, TP4.1, U4.1 (GND), U5.2 (GND), U6.3 (GND), U6.7 (A0), U6.8 (A1), U7.3 (GND), U7.8 (A1); also elsewhere on the board
I2C_SCL: U6.5 (SCL), U7.5 (SCL); also elsewhere on the board
I2C_SDA: U6.6 (SDA), U7.6 (SDA); also elsewhere on the board
unnamed: D4.1 (K), R20.2
unnamed: Q1.2 (D), Q3.2 (D)
unnamed: C12.2, Q1.1 (G), Q3.1 (G), R14.2, R15.1
unnamed: Q2.1 (B), R16.1, R17.2
unnamed: R18.1, R19.2, U4.4 (PR1)
unnamed: R20.1, U4.8 (ST)
unnamed: C20.1, R21.2, U6.1 (IN+)
unnamed: C20.2, R23.1, U6.2 (IN-)
unnamed: C21.1, R24.1, U7.1 (IN+)
unnamed: C21.2, R26.1, U7.2 (IN-)
TO_CONVERTER: J4.2, R22.1, R23.2
USB_VBUS: C14.1, U4.6 (VIN2); also elsewhere on the board
VIN_5V: C13.1, C17.2, C19.2, D3.2 (A), R18.2, U4.3 (VIN1), U4.5 (MODE), U5.3 (OUT)
VREF_THERMISTOR: R13.1, TH1.1; also elsewhere on the board

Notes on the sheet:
MULTIPLEXER
THERMAL MONITOR
ノイズなど，必要に応じて実装
CURRENT MONITOR
POWER INPUT DC JACK 15-24V
LINER REGULATOR 5V
CONVERTER
LOAD SWITCH

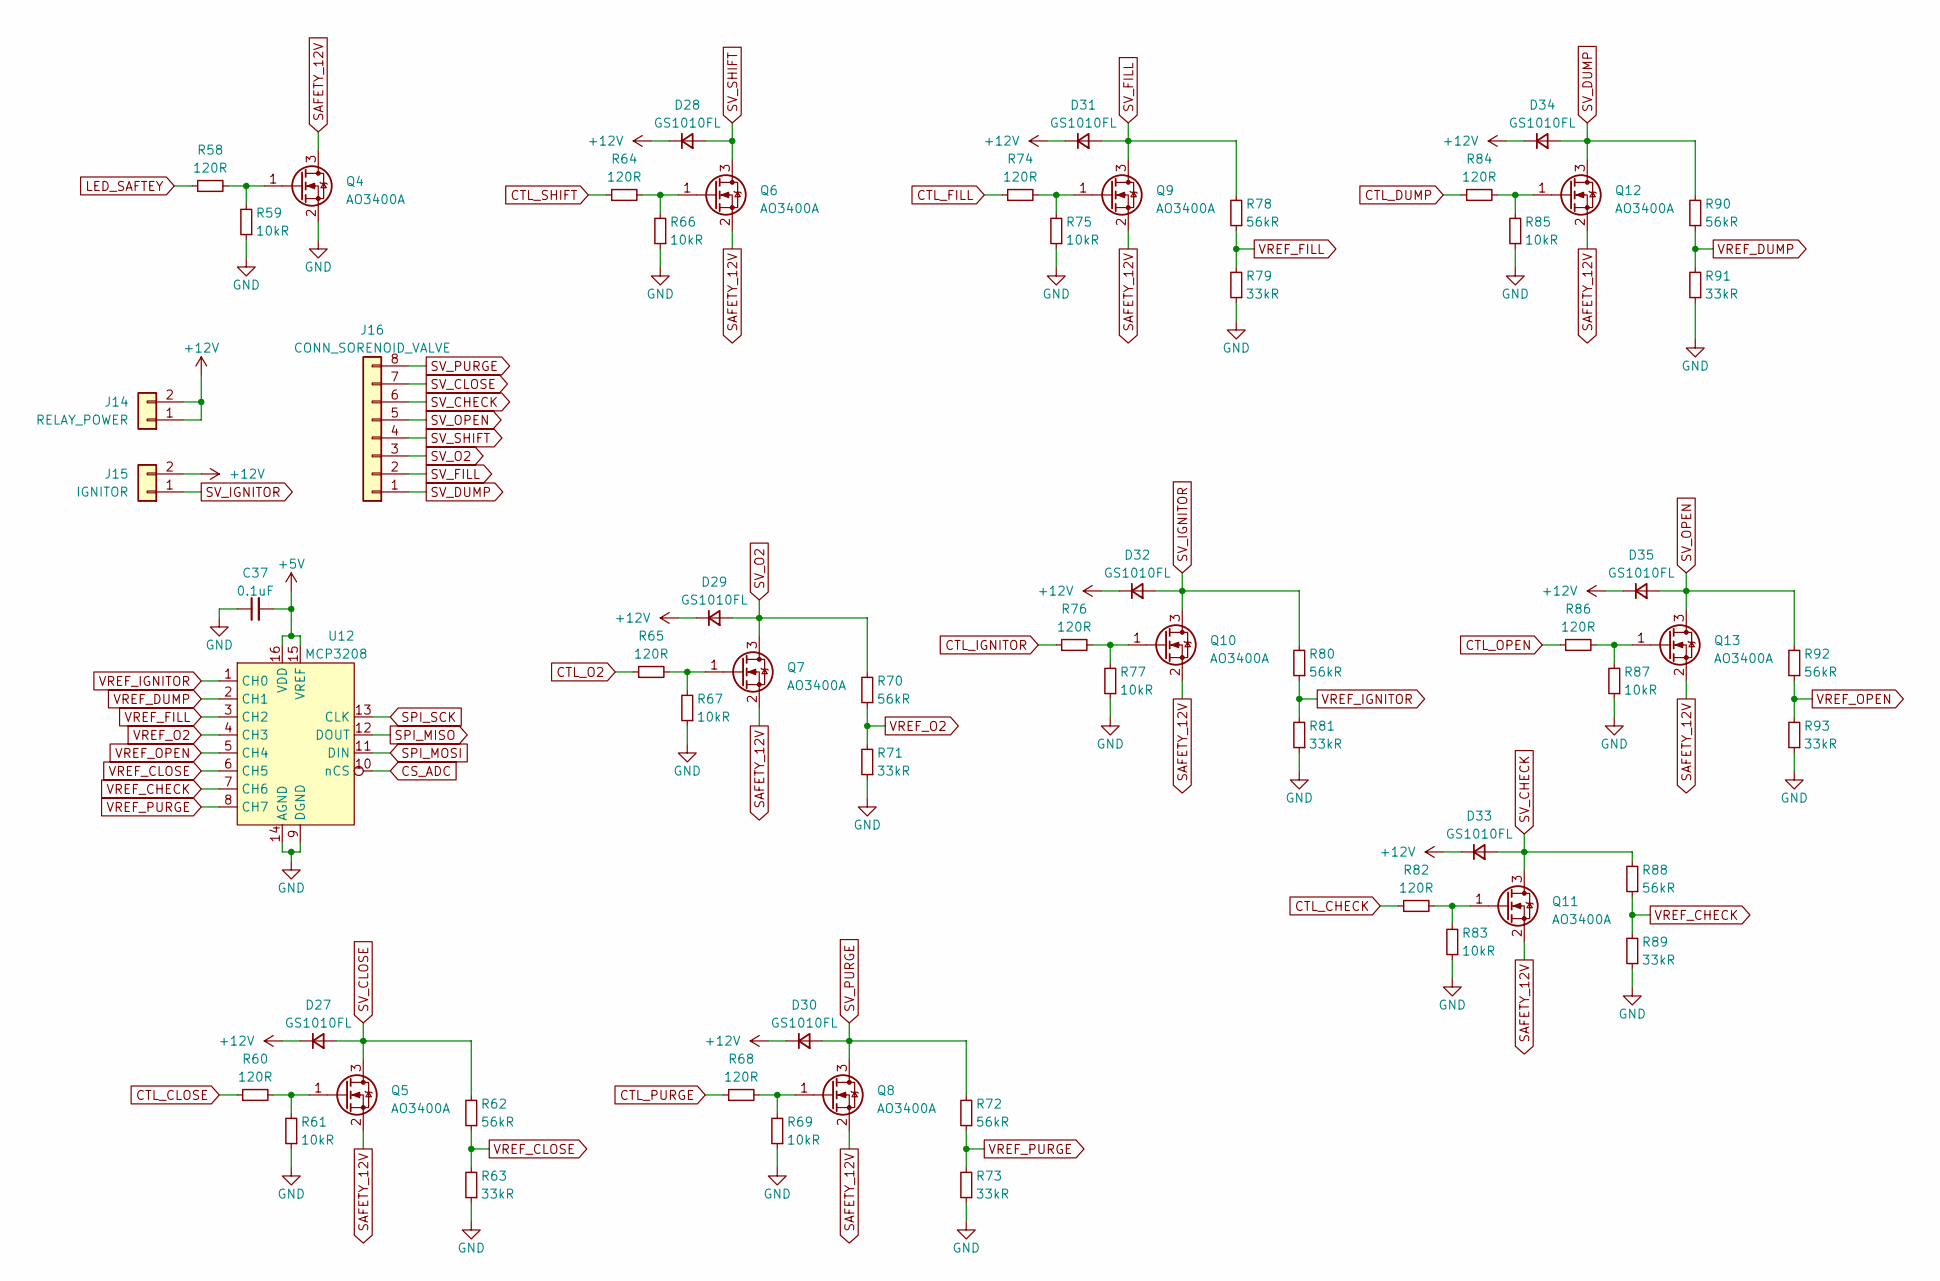
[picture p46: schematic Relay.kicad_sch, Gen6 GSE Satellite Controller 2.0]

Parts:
C37: 0.1uF; C_0603_1608Metric_Pad1.08x0.95mm_HandSolder
D27, D28, D29, D30, D31, D32, D33, D34, D35: GS1010FL; D_SOD-123F
J14: RELAY_POWER; TerminalBlock_WAGO_2601-3102_1x02_P3.50mm_Vertical; Digikey_PN 2946-2601-3102-ND
J15: IGNITOR; TerminalBlock_WAGO_2601-3102_1x02_P3.50mm_Vertical; Digikey_PN 2946-2601-3102-ND
J16: CONN_SORENOID_VALVE; DF51A-8DP-2DS; Mouser_PN 798-DF51A-8DP-2DSA
Q4, Q5, Q6, Q7, Q8, Q9, Q10, Q11, Q12, Q13: AO3400A; SOT-23; Digikey_PN 785-1000-1-ND
R58, R60, R64, R65, R68, R74, R76, R82, R84, R86: 120R; R_0603_1608Metric_Pad0.98x0.95mm_HandSolder; Digikey_PN 2019-RK73H1JTTD1200FCT-ND
R59, R61, R66, R67, R69, R75, R77, R83, R85, R87: 10kR; R_0603_1608Metric_Pad0.98x0.95mm_HandSolder; Digikey_PN 2019-RK73H1JTTD1002FCT-ND
R62, R70, R72, R78, R80, R88, R90, R92: 56kR; R_0603_1608Metric_Pad0.98x0.95mm_HandSolder; Digikey_PN 2019-RK73H1JTTD5602FCT-ND
R63, R71, R73, R79, R81, R89, R91, R93: 33kR; R_0603_1608Metric_Pad0.98x0.95mm_HandSolder; Digikey_PN 2019-RK73H1JTTD3302FCT-ND
U12: MCP3208; DIP-16_W7.62mm

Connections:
CONN_LED_5V: C37.2, U12.15 (VREF), U12.16 (VDD); also elsewhere on the board
CONN_LED_12V: D27.1 (K), D28.1 (K), D29.1 (K), D30.1 (K), D31.1 (K), D32.1 (K), D33.1 (K), D34.1 (K), D35.1 (K), J14.1, J14.2, J15.2; also elsewhere on the board
CONN_LED_SAFTEY: R58.1; also elsewhere on the board
CS_ADC: U12.10 (nCS); also elsewhere on the board
CTL_CHECK: R82.1; also elsewhere on the board
CTL_CLOSE: R60.1; also elsewhere on the board
CTL_DUMP: R84.1; also elsewhere on the board
CTL_FILL: R74.1; also elsewhere on the board
CTL_IGNITOR: R76.1; also elsewhere on the board
CTL_O2: R65.1; also elsewhere on the board
CTL_OPEN: R86.1; also elsewhere on the board
CTL_PURGE: R68.1; also elsewhere on the board
CTL_SHIFT: R64.1; also elsewhere on the board
GND: C37.1, Q4.2 (S), R59.1, R61.1, R63.1, R66.1, R67.1, R69.1, R71.1, R73.1, R75.1, R77.1, R79.1, R81.1, R83.1, R85.1, R87.1, R89.1, R91.1, R93.1, U12.9 (DGND), U12.14 (AGND); also elsewhere on the board
unnamed: Q4.1 (G), R58.2, R59.2
unnamed: Q5.1 (G), R60.2, R61.2
unnamed: Q6.1 (G), R64.2, R66.2
unnamed: Q7.1 (G), R65.2, R67.2
unnamed: Q8.1 (G), R68.2, R69.2
unnamed: Q9.1 (G), R74.2, R75.2
unnamed: Q10.1 (G), R76.2, R77.2
unnamed: Q11.1 (G), R82.2, R83.2
unnamed: Q12.1 (G), R84.2, R85.2
unnamed: Q13.1 (G), R86.2, R87.2
SAFETY_12V: Q4.3 (D), Q5.2 (S), Q6.2 (S), Q7.2 (S), Q8.2 (S), Q9.2 (S), Q10.2 (S), Q11.2 (S), Q12.2 (S), Q13.2 (S)
SPI_MISO: U12.12 (DOUT); also elsewhere on the board
SPI_MOSI: U12.11 (DIN); also elsewhere on the board
SPI_SCK: U12.13 (CLK); also elsewhere on the board
SV_CHECK: D33.2 (A), J16.6, Q11.3 (D), R88.2
SV_CLOSE: D27.2 (A), J16.7, Q5.3 (D), R62.2
SV_DUMP: D34.2 (A), J16.1, Q12.3 (D), R90.2
SV_FILL: D31.2 (A), J16.2, Q9.3 (D), R78.2
SV_IGNITOR: D32.2 (A), J15.1, Q10.3 (D), R80.2
SV_O2: D29.2 (A), J16.3, Q7.3 (D), R70.2
SV_OPEN: D35.2 (A), J16.5, Q13.3 (D), R92.2
SV_PURGE: D30.2 (A), J16.8, Q8.3 (D), R72.2
SV_SHIFT: D28.2 (A), J16.4, Q6.3 (D)
VREF_CHECK: R88.1, R89.2, U12.7 (CH6)
VREF_CLOSE: R62.1, R63.2, U12.6 (CH5)
VREF_DUMP: R90.1, R91.2, U12.2 (CH1)
VREF_FILL: R78.1, R79.2, U12.3 (CH2)
VREF_IGNITOR: R80.1, R81.2, U12.1 (CH0)
VREF_O2: R70.1, R71.2, U12.4 (CH3)
VREF_OPEN: R92.1, R93.2, U12.5 (CH4)
VREF_PURGE: R72.1, R73.2, U12.8 (CH7)

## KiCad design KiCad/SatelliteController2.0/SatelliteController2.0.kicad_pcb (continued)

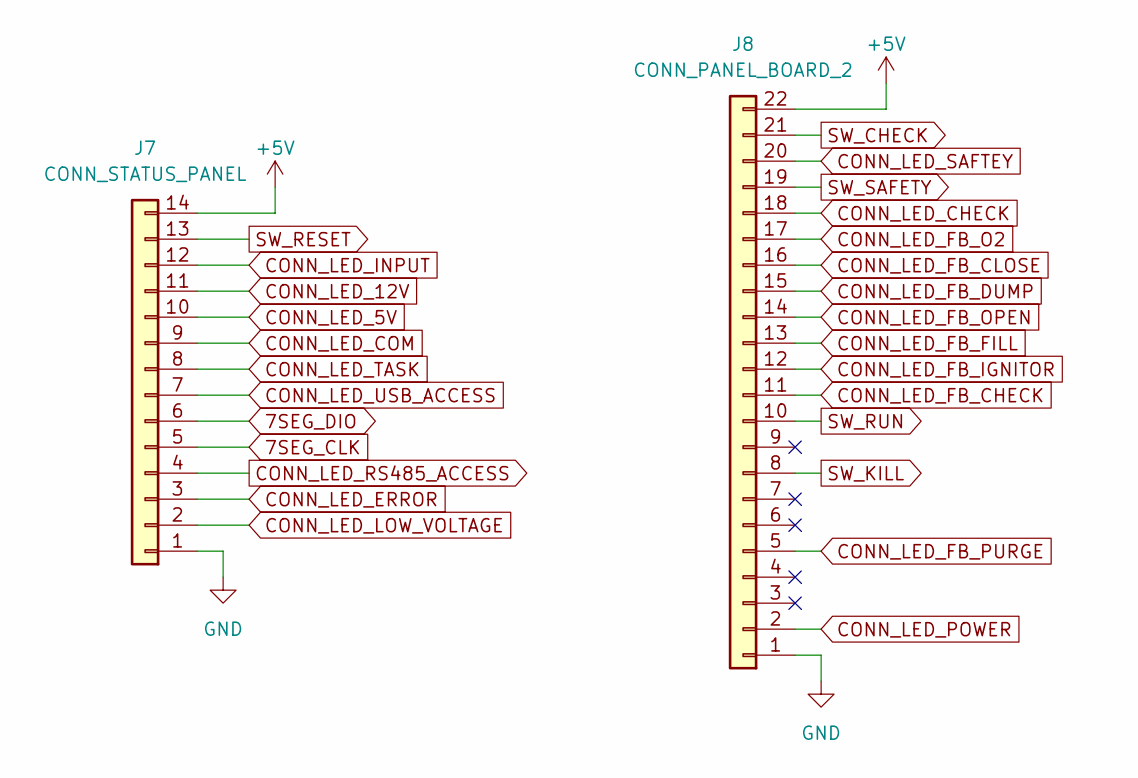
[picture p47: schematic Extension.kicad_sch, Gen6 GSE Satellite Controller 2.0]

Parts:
J7: CONN_STATUS_PANEL; DF51A-14DP-2DS; Digikey_PN 2946-2601-3104-ND
J8: CONN_PANEL_BOARD_2; DF51A-22DP-2DS; Digikey_PN 2946-2601-3104-ND

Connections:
7SEG_CLK: J7.5; also elsewhere on the board
7SEG_DIO: J7.6; also elsewhere on the board
CONN_LED_5V: J7.10, J7.14, J8.22; also elsewhere on the board
CONN_LED_12V: J7.11; also elsewhere on the board
CONN_LED_CHECK: J8.18; also elsewhere on the board
CONN_LED_COM: J7.9; also elsewhere on the board
CONN_LED_ERROR: J7.3; also elsewhere on the board
CONN_LED_FB_CHECK: J8.11
CONN_LED_INPUT: J7.12; also elsewhere on the board
CONN_LED_LOW_VOLTAGE: J7.2; also elsewhere on the board
CONN_LED_RS485_ACCESS: J7.4; also elsewhere on the board
CONN_LED_SAFTEY: J8.20; also elsewhere on the board
CONN_LED_TASK: J7.8; also elsewhere on the board
CONN_LED_USB_ACCESS: J7.7; also elsewhere on the board
CTL_CHECK: J8.21; also elsewhere on the board
CTL_KILL: J8.8; also elsewhere on the board
CTL_RESET: J7.13; also elsewhere on the board
CTL_RUN: J8.10; also elsewhere on the board
CTL_SAFETY: J8.19; also elsewhere on the board
GND: J7.1, J8.1; also elsewhere on the board

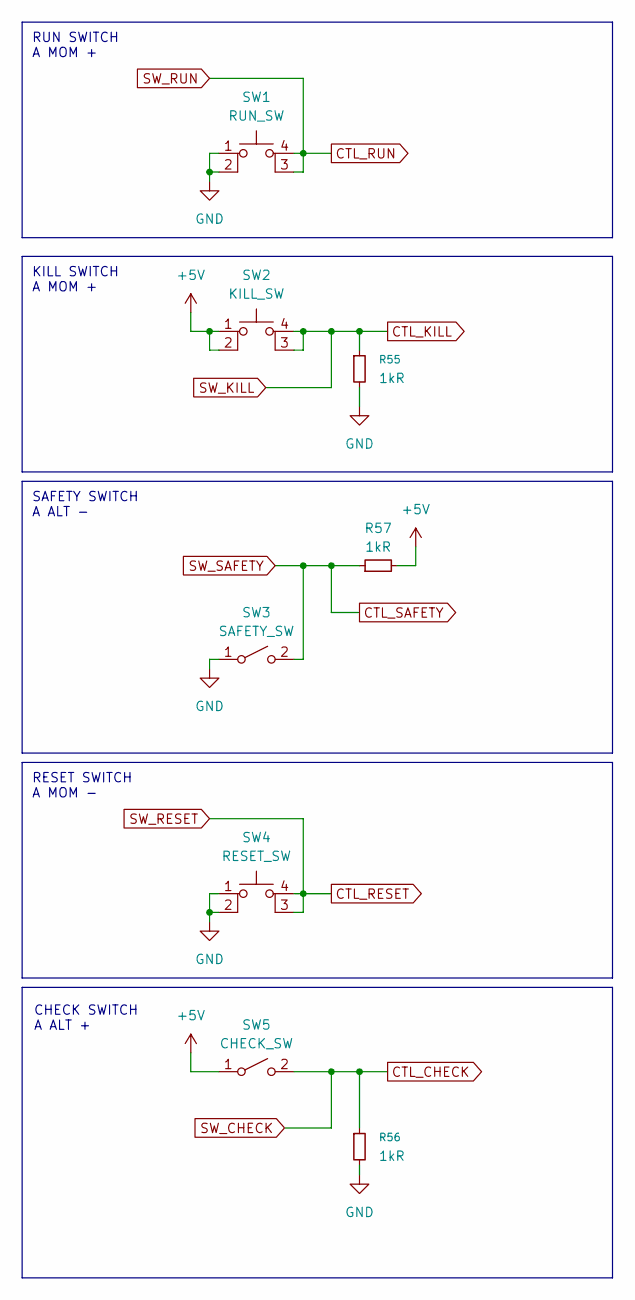
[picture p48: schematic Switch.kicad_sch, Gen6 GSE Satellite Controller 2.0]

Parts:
R55, R56, R57: 1kR; R_0603_1608Metric_Pad0.98x0.95mm_HandSolder; Digikey_PN 2019-RK73H1JTTD1001FCT-ND
SW1: RUN_SW; SKRPACE010
SW2: KILL_SW; SKRPACE010
SW3: SAFETY_SW; PinHeader_1x02_P2.54mm_Vertical
SW4: RESET_SW; SKRPACE010
SW5: CHECK_SW; PinHeader_1x02_P2.54mm_Vertical

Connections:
CONN_LED_5V: R57.2, SW2.1, SW2.2, SW5.1 (A); also elsewhere on the board
CTL_CHECK: R56.1, SW5.2 (B); also elsewhere on the board
CTL_KILL: R55.1, SW2.3 (K), SW2.4 (A); also elsewhere on the board
CTL_RESET: SW4.3 (K), SW4.4 (A); also elsewhere on the board
CTL_RUN: SW1.3 (K), SW1.4 (A); also elsewhere on the board
CTL_SAFETY: R57.1, SW3.2 (B); also elsewhere on the board
GND: R55.2, R56.2, SW1.1, SW1.2, SW3.1 (A), SW4.1, SW4.2; also elsewhere on the board

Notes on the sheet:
KILL SWITCH A MOM +
RUN SWITCH A MOM +
CHECK SWITCH A ALT +
RESET SWITCH A MOM -
SAFETY SWITCH A ALT -

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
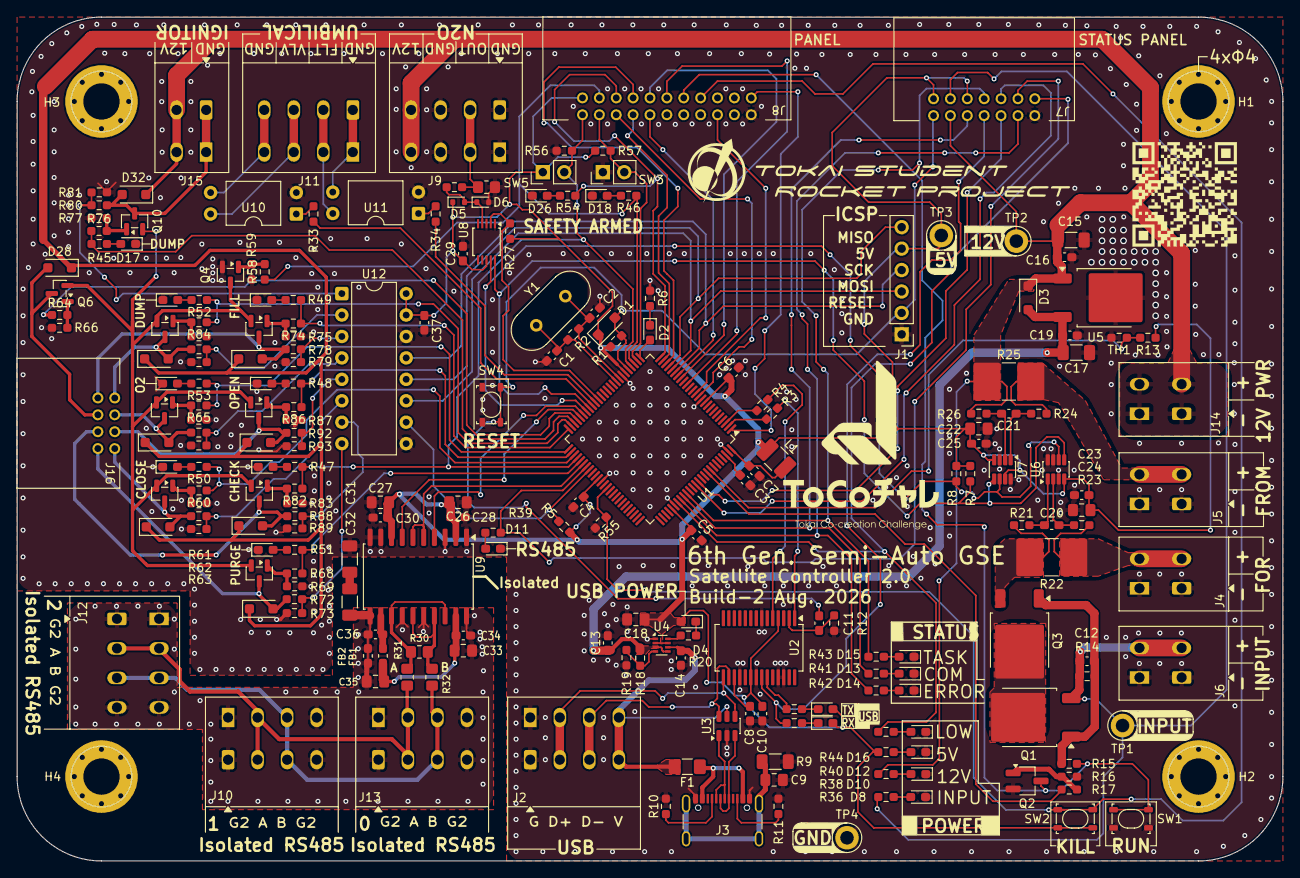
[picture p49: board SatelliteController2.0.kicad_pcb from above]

Board: 2 copper layers, 150.0 x 100.0 mm, 225 parts (0 on the bottom side), 149 nets.

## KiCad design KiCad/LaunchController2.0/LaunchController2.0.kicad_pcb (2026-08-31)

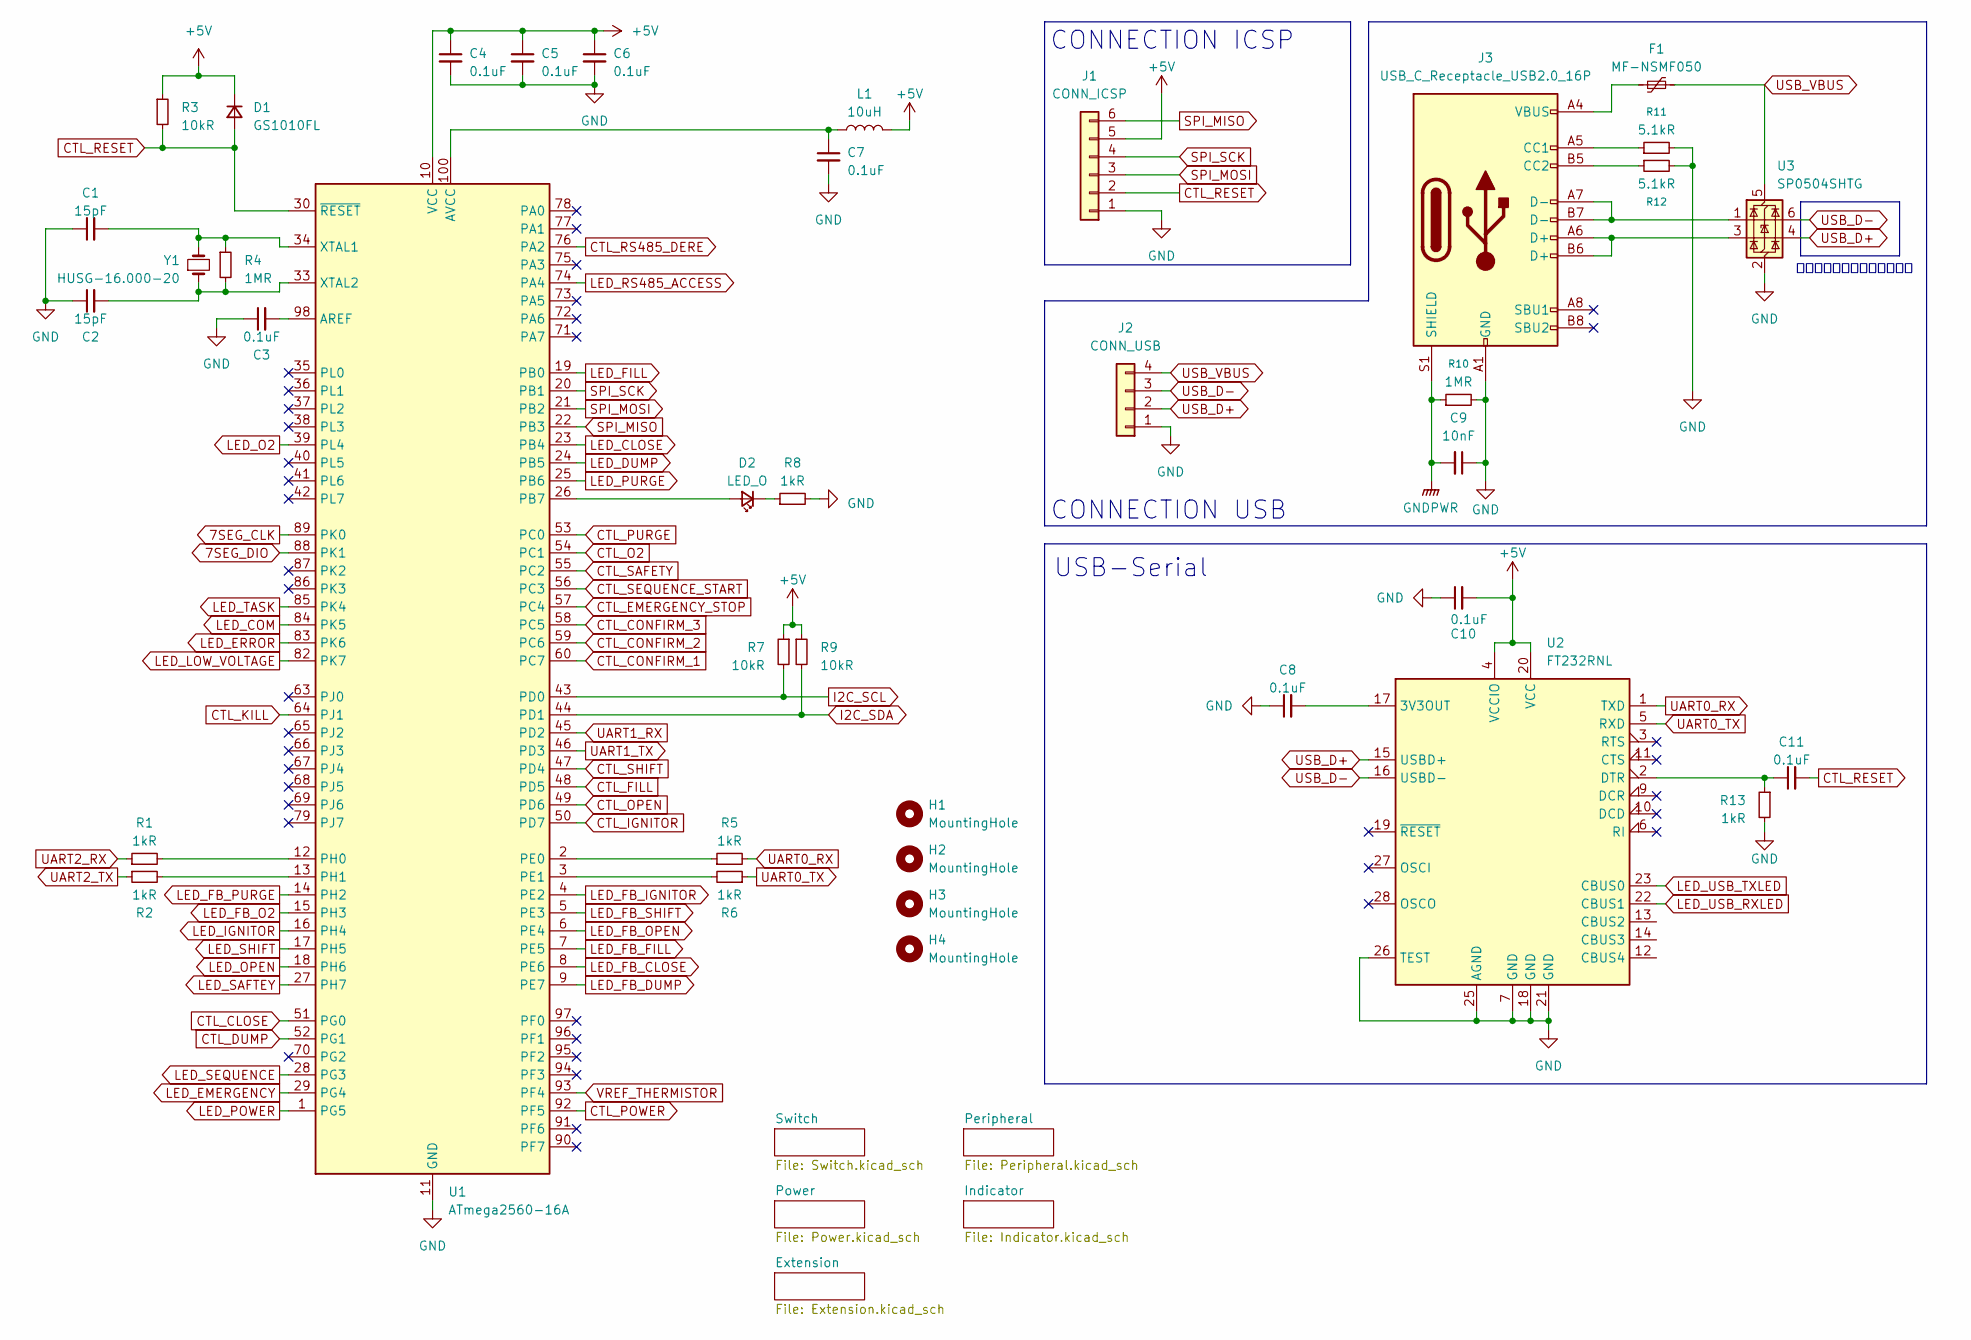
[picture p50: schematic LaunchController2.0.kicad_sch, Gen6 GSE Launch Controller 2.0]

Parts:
C1, C2: 15pF; C_0603_1608Metric_Pad1.08x0.95mm_HandSolder
C3, C4, C5, C6, C7, C8, C10, C11: 0.1uF; C_0603_1608Metric_Pad1.08x0.95mm_HandSolder
C9: 10nF; C_0805_2012Metric_Pad1.18x1.45mm_HandSolder; Digikey_PN 490-GCM21B5C2E103FX0ALCT-ND
D1: GS1010FL; D_SOD-123F
D2: LED_O; LED_0603_1608Metric_Pad1.05x0.95mm_HandSolder; Digikey_PN SML-D15DWT86CCT-ND
F1: MF-NSMF050; Fuse_1206_3216Metric_Pad1.42x1.75mm_HandSolder
H1, H2, H3, H4: MountingHole; MountingHole_4.3mm_M4_Pad_Via
J1: CONN_ICSP; PinHeader_1x06_P2.54mm_Vertical
J2: CONN_USB; TerminalBlock_WAGO_2601-3104_1x04_P3.50mm_Vertical; Digikey_PN 2946-2601-3104-ND
J3: USB_C_Receptacle_USB2.0_16P; USB_C_Receptacle_GCT_USB4105-xx-A_16P_TopMnt_Horizontal
L1: 10uH; L_1210_3225Metric_Pad1.42x2.65mm_HandSolder
R1, R2, R5, R6, R8, R13: 1kR; R_0603_1608Metric_Pad0.98x0.95mm_HandSolder; Digikey_PN 2019-RK73H1JTTD1001FCT-ND
R3, R7, R9: 10kR; R_0603_1608Metric_Pad0.98x0.95mm_HandSolder; Digikey_PN 2019-RK73H1JTTD1002FCT-ND
R4: 1MR; R_0603_1608Metric_Pad0.98x0.95mm_HandSolder; Digikey_PN 2019-RK73H1JTTD1004FCT-ND
R10: 1MR; R_1206_3216Metric_Pad1.30x1.75mm_HandSolder; Digikey_PN 2019-RK73H2BTTD1004FCT-ND
R11, R12: 5.1kR; R_0603_1608Metric_Pad0.98x0.95mm_HandSolder; Digikey_PN 2019-RK73H1JTTD5101FCT-ND
U1: ATmega2560-16A; TQFP-100_14x14mm_P0.5mm
U2: FT232RNL; SSOP-28_5.3x10.2mm_P0.65mm
U3: SP0504SHTG; SOT-23-6; Digikey_PN F5775CT-ND
Y1: HUSG-16.000-20; Crystal_HC49-4H_Vertical

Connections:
7SEG_CLK: U1.89 (PK0); also elsewhere on the board
7SEG_DIO: U1.88 (PK1); also elsewhere on the board
CONN_LED_5V: C4.1, C5.1, C6.1, C10.2, D1.1 (K), J1.5, L1.2, R3.1, R7.1, R9.1, U1.10 (VCC), U1.31 (VCC), U1.61 (VCC), U1.80 (VCC), U2.4 (VCCIO), U2.20 (VCC); also elsewhere on the board
CONN_LED_CLOSE: U1.23 (PB4); also elsewhere on the board
CONN_LED_COM: U1.84 (PK5); also elsewhere on the board
CONN_LED_DUMP: U1.24 (PB5); also elsewhere on the board
CONN_LED_EMERGENCY: U1.29 (PG4); also elsewhere on the board
CONN_LED_ERROR: U1.83 (PK6); also elsewhere on the board
CONN_LED_FILL: U1.19 (PB0); also elsewhere on the board
CONN_LED_IGNITOR: U1.16 (PH4); also elsewhere on the board
CONN_LED_LOW_VOLTAGE: U1.82 (PK7); also elsewhere on the board
CONN_LED_O2: U1.39 (PL4); also elsewhere on the board
CONN_LED_OPEN: U1.18 (PH6); also elsewhere on the board
CONN_LED_PURGE: U1.25 (PB6); also elsewhere on the board
CONN_LED_RS485_ACCESS: U1.74 (PA4); also elsewhere on the board
CONN_LED_SAFTEY: U1.27 (PH7); also elsewhere on the board
CONN_LED_SEQUENCE: U1.28 (PG3); also elsewhere on the board
CONN_LED_SHIFT: U1.17 (PH5); also elsewhere on the board
CONN_LED_TASK: U1.85 (PK4); also elsewhere on the board
CONN_LED_USB_ACCESS: U2.22 (CBUS1); also elsewhere on the board
CTL_CLOSE: U1.51 (PG0); also elsewhere on the board
CTL_CONFIRM_1: U1.60 (PC7); also elsewhere on the board
CTL_CONFIRM_2: U1.59 (PC6); also elsewhere on the board
CTL_CONFIRM_3: U1.58 (PC5); also elsewhere on the board
CTL_DUMP: U1.52 (PG1); also elsewhere on the board
CTL_EMERGENCY_STOP: U1.57 (PC4); also elsewhere on the board
CTL_FILL: U1.48 (PD5); also elsewhere on the board
CTL_IGNITOR: U1.50 (PD7); also elsewhere on the board
CTL_KILL: U1.64 (PJ1); also elsewhere on the board
CTL_O2: U1.54 (PC1); also elsewhere on the board
CTL_OPEN: U1.49 (PD6); also elsewhere on the board
CTL_POWER: U1.92 (PF5); also elsewhere on the board
CTL_PURGE: U1.53 (PC0); also elsewhere on the board
CTL_RESET: C11.2, D1.2 (A), J1.2, R3.2, U1.30 (~RESET); also elsewhere on the board
CTL_RS485_DERE: U1.76 (PA2); also elsewhere on the board
CTL_SAFETY: U1.55 (PC2); also elsewhere on the board
CTL_SEQUENCE_START: U1.56 (PC3); also elsewhere on the board
CTL_SHIFT: U1.47 (PD4); also elsewhere on the board
GND: C1.1, C2.1, C3.1, C4.2, C5.2, C6.2, C7.2, C8.1, C9.1, C10.1, J1.1, J2.1, J3.A1 (GND), J3.A12 (GND), J3.B1 (GND), J3.B12 (GND), R8.2, R10.2, R11.2, R12.2, R13.2, U1.11 (GND), U1.32 (GND), U1.62 (GND), U1.81 (GND), U1.99 (GND), U2.7 (GND), U2.18 (GND), U2.21 (GND), U2.25 (AGND), U2.26 (TEST), U3.2 (GND); also elsewhere on the board
GNDPWR: C9.2, J3.S1 (SHIELD), R10.1
I2C_SCL: R7.2, U1.43 (PD0); also elsewhere on the board
I2C_SDA: R9.2, U1.44 (PD1); also elsewhere on the board
LED_USB_TXLED: U2.23 (CBUS0); also elsewhere on the board
unnamed: D2.2 (A), U1.26 (PB7)
unnamed: D2.1 (K), R8.1
unnamed: F1.1, J3.A4 (VBUS), J3.A9 (VBUS), J3.B4 (VBUS), J3.B9 (VBUS)
unnamed: J3.A5 (CC1), R11.1
unnamed: J3.B5 (CC2), R12.1
unnamed: J3.A6 (D+), J3.B6 (D+), U3.3 (I/O2)
unnamed: J3.A7 (D-), J3.B7 (D-), U3.1 (I/O1)
unnamed: C3.2, U1.98 (AREF)
unnamed: C7.1, L1.1, U1.100 (AVCC)
unnamed: R5.1, U1.2 (PE0)
unnamed: R6.2, U1.3 (PE1)
unnamed: R1.2, U1.12 (PH0)
unnamed: R2.2, U1.13 (PH1)
unnamed: C1.2, R4.1, U1.34 (XTAL1), Y1.2
unnamed: C2.2, R4.2, U1.33 (XTAL2), Y1.1
unnamed: C8.2, U2.17 (3V3OUT)
unnamed: C11.1, R13.1, U2.2 (DTR)
SPI_MISO: J1.6, U1.22 (PB3)
SPI_MOSI: J1.3, U1.21 (PB2)
SPI_SCK: J1.4, U1.20 (PB1)
UART0_RX: R5.2, U2.1 (TXD)
UART0_TX: R6.1, U2.5 (RXD)
UART1_RX: U1.45 (PD2); also elsewhere on the board
UART1_TX: U1.46 (PD3); also elsewhere on the board
UART2_RX: R1.1; also elsewhere on the board
UART2_TX: R2.1; also elsewhere on the board
USB_D+: J2.2, U2.15 (USBD+), U3.4 (I/O2)
USB_D-: J2.3, U2.16 (USBD-), U3.6 (I/O1)
USB_VBUS: F1.2, J2.4, U3.5 (VBUS); also elsewhere on the board
VREF_THERMISTOR: U1.93 (PF4); also elsewhere on the board

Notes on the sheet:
CONNECTION ICSP
USB-Serial
配線（符号）に気をつけよう
CONNECTION USB

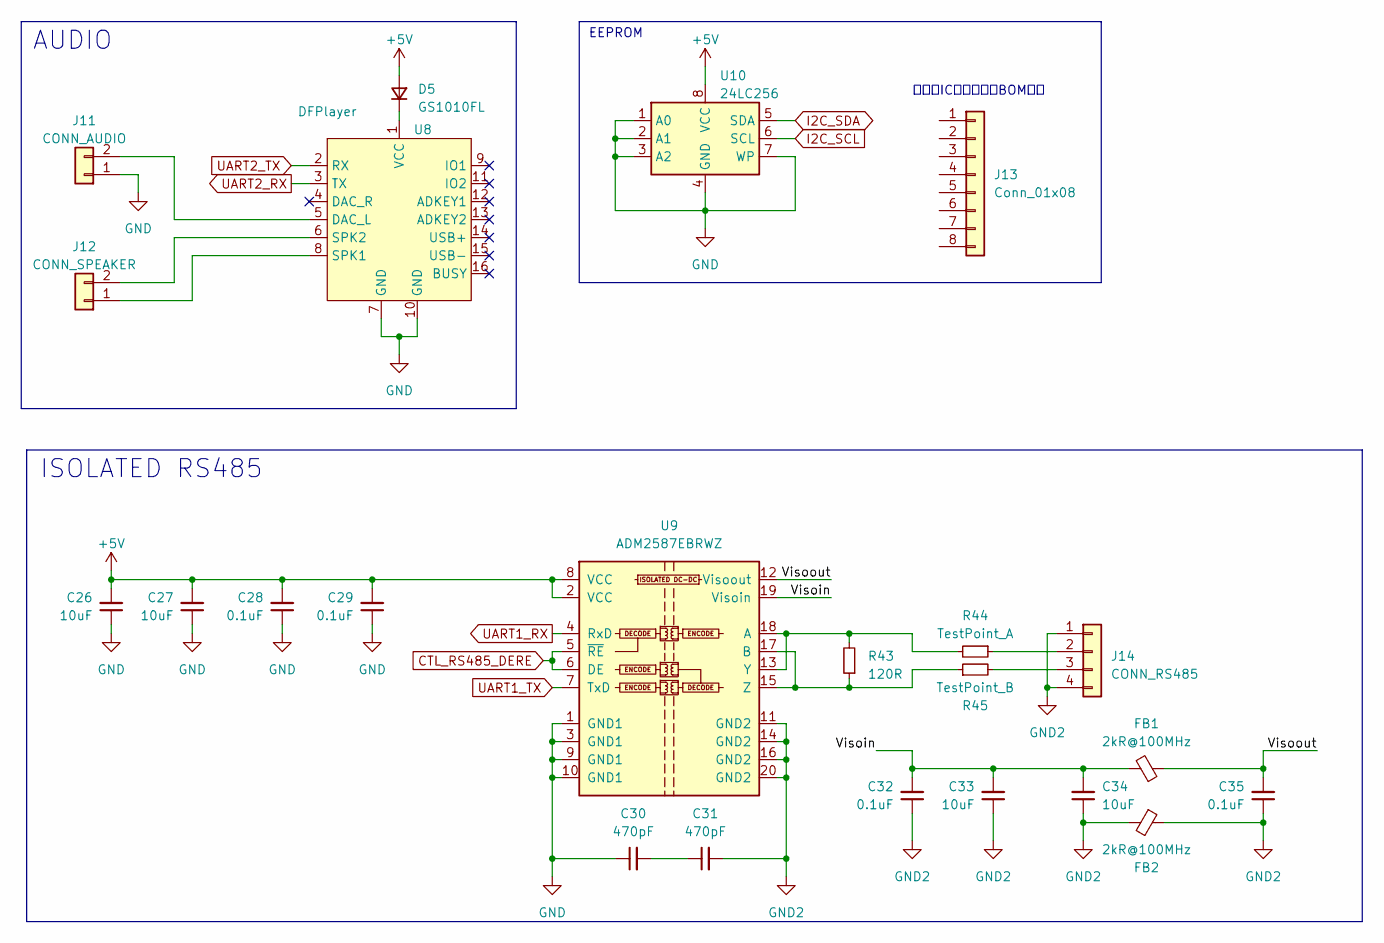
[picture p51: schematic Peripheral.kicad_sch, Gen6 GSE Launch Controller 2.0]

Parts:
C26, C27, C33, C34: 10uF; C_0805_2012Metric_Pad1.18x1.45mm_HandSolder
C28, C29, C32, C35: 0.1uF; C_0603_1608Metric_Pad1.08x0.95mm_HandSolder
C30, C31: 470pF; C_1206_3216Metric_Pad1.33x1.80mm_HandSolder; Digikey_PN 445-5785-1-ND
D5: GS1010FL; D_SOD-123F
FB1, FB2: 2kR@100MHz; L_0603_1608Metric_Pad1.05x0.95mm_HandSolder; Digikey_PN 445-MMZ1608S202ATA00CT-ND
J11: CONN_AUDIO; TerminalBlock_WAGO_2601-3102_1x02_P3.50mm_Vertical; Digikey_PN 2946-2601-3102-ND
J12: CONN_SPEAKER; TerminalBlock_WAGO_2601-3102_1x02_P3.50mm_Vertical; Digikey_PN 2946-2601-3102-ND
J13: Conn_01x08
J14: CONN_RS485; TerminalBlock_WAGO_2601-3104_1x04_P3.50mm_Vertical; Digikey_PN 2946-2601-3104-ND
R43: 120R; R_0805_2012Metric_Pad1.20x1.40mm_HandSolder; Digikey_PN 2019-RK73H2ATTD1200FCT-ND
R44: TestPoint_A; R_0805_2012Metric
R45: TestPoint_B; R_0805_2012Metric
U8: DFPlayer; DFPlayer-mini
U9: ADM2587EBRWZ; SOIC-20W_7.5x12.8mm_P1.27mm
U10: 24LC256; DIP-8_W7.62mm

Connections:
/Peripheral/Visoin: C32.2, C33.2, C34.2, FB1.2, U9.19 (Visoin)
/Peripheral/Visoout: C35.2, FB1.1, U9.12 (Visoout)
CONN_LED_5V: C26.2, C27.2, C28.2, C29.2, D5.2 (A), U9.2 (VCC), U9.8 (VCC), U10.8 (VCC); also elsewhere on the board
CTL_RS485_DERE: U9.5 (~RE), U9.6 (DE); also elsewhere on the board
GND: C26.1, C27.1, C28.1, C29.1, C30.1, J11.1, U8.7 (GND), U8.10 (GND), U9.1 (GND1), U9.3 (GND1), U9.9 (GND1), U9.10 (GND1), U10.1 (A0), U10.2 (A1), U10.3 (A2), U10.4 (GND), U10.7 (WP); also elsewhere on the board
GND2: C31.2, C32.1, C33.1, C34.1, C35.1, FB2.1, FB2.2, J14.1, J14.4, U9.11 (GND2), U9.14 (GND2), U9.16 (GND2), U9.20 (GND2)
I2C_SCL: U10.6 (SCL); also elsewhere on the board
I2C_SDA: U10.5 (SDA); also elsewhere on the board
unnamed: C30.2, C31.1
unnamed: D5.1 (K), U8.1 (VCC)
unnamed: J11.2, U8.5 (DAC_L)
unnamed: J12.1, U8.8 (SPK1)
unnamed: J12.2, U8.6 (SPK2)
unnamed: J14.2, R44.1
unnamed: J14.3, R45.2
unnamed: R43.2, R44.2, U9.13 (Y), U9.18 (A)
unnamed: R43.1, R45.1, U9.15 (Z), U9.17 (B)
UART1_RX: U9.4 (RxD); also elsewhere on the board
UART1_TX: U9.7 (TxD); also elsewhere on the board
UART2_RX: U8.3 (TX); also elsewhere on the board
UART2_TX: U8.2 (RX); also elsewhere on the board

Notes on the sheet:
ISOLATED RS485
AUDIO
丸ピンICソケット（BOM用）
EEPROM

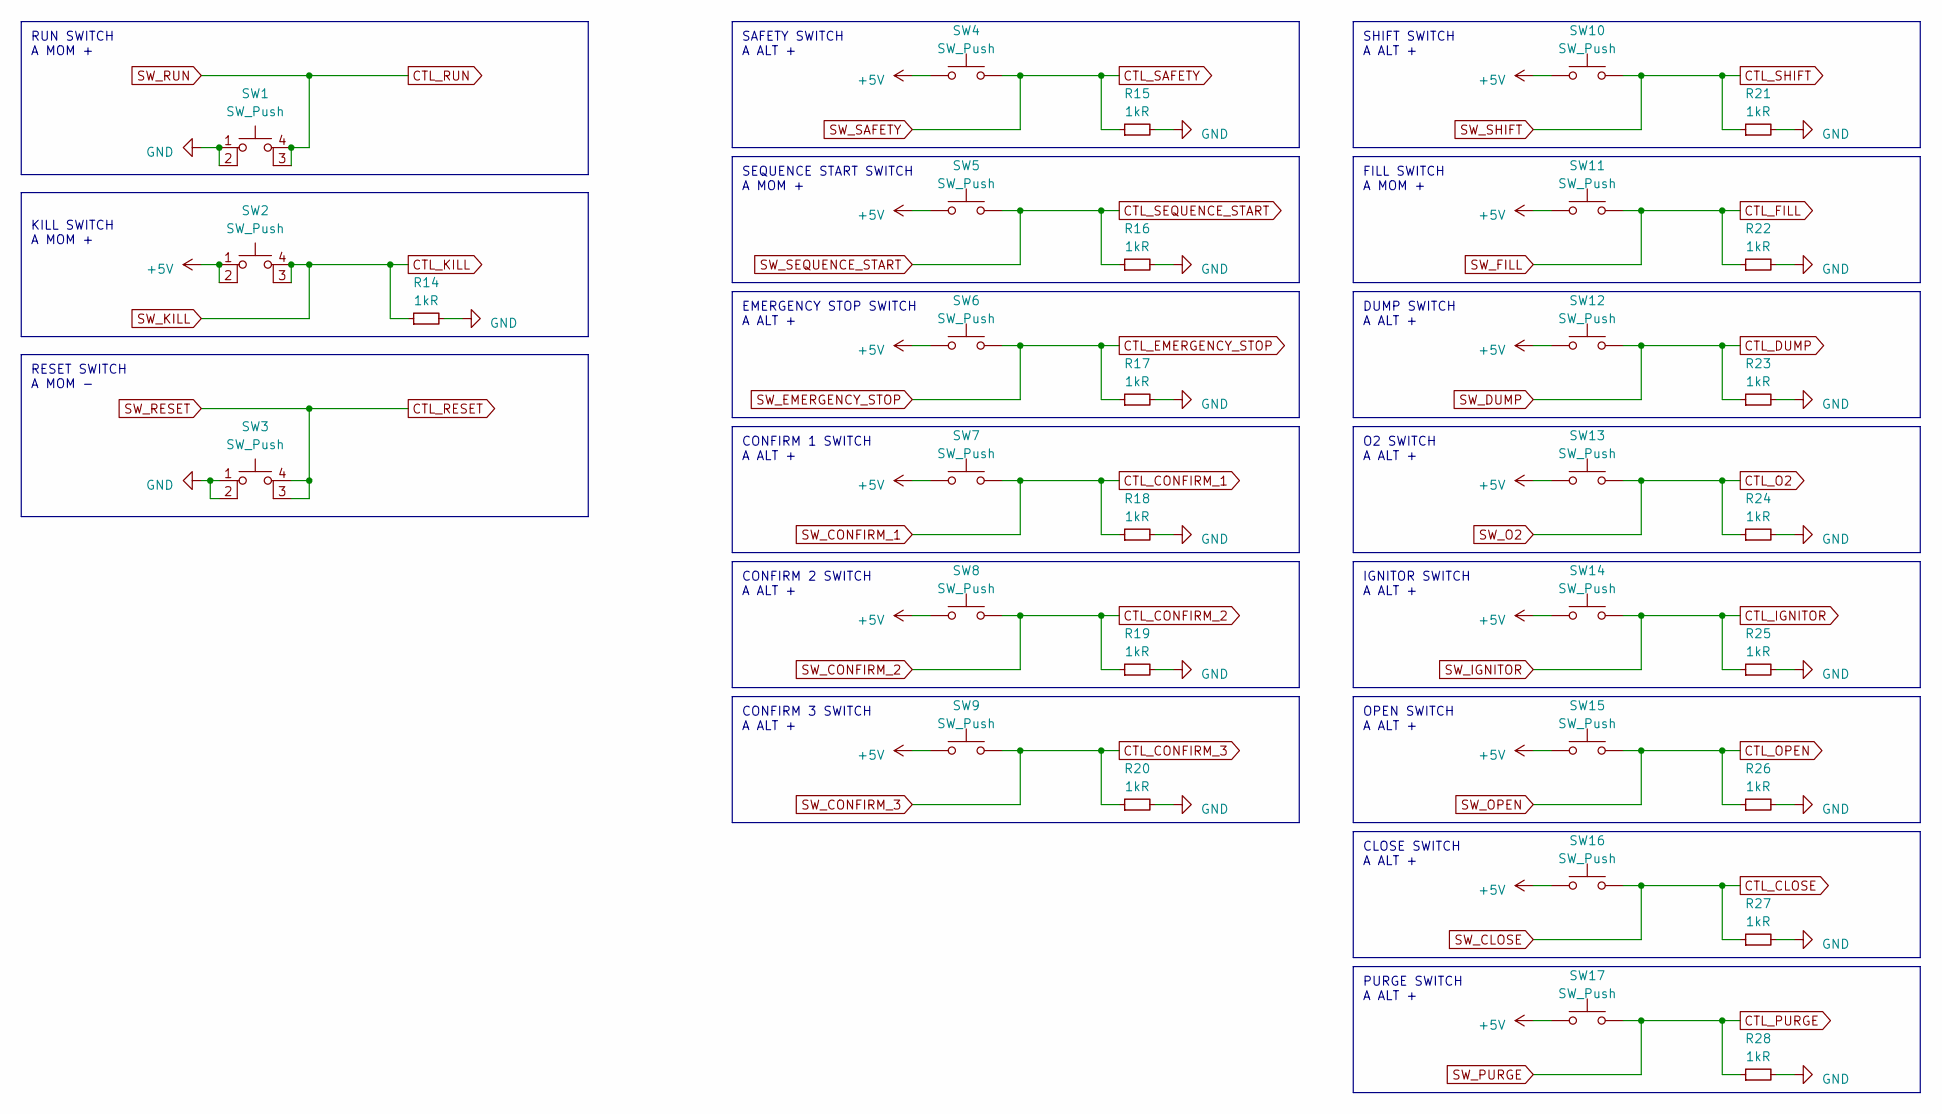
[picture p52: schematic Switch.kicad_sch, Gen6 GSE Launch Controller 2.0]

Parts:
R14, R15, R16, R17, R18, R19, R20, R21, R22, R23, R24, R25, R26, R27, R28: 1kR; R_0603_1608Metric_Pad0.98x0.95mm_HandSolder; Digikey_PN 2019-RK73H1JTTD1001FCT-ND
SW1, SW2, SW3: SW_Push; SKRPACE010
SW4, SW5, SW6, SW7, SW8, SW9, SW10, SW11, SW12, SW13, SW14, SW15, SW16, SW17: SW_Push; PinHeader_1x02_P2.54mm_Vertical

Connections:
CONN_LED_5V: SW2.1, SW2.2, SW4.1, SW5.1, SW6.1, SW7.1, SW8.1, SW9.1, SW10.1, SW11.1, SW12.1, SW13.1, SW14.1, SW15.1, SW16.1, SW17.1; also elsewhere on the board
CTL_CLOSE: R27.1, SW16.2; also elsewhere on the board
CTL_CONFIRM_1: R18.1, SW7.2; also elsewhere on the board
CTL_CONFIRM_2: R19.1, SW8.2; also elsewhere on the board
CTL_CONFIRM_3: R20.1, SW9.2; also elsewhere on the board
CTL_DUMP: R23.1, SW12.2; also elsewhere on the board
CTL_EMERGENCY_STOP: R17.1, SW6.2; also elsewhere on the board
CTL_FILL: R22.1, SW11.2; also elsewhere on the board
CTL_IGNITOR: R25.1, SW14.2; also elsewhere on the board
CTL_KILL: R14.1, SW2.3 (K), SW2.4 (A); also elsewhere on the board
CTL_O2: R24.1, SW13.2; also elsewhere on the board
CTL_OPEN: R26.1, SW15.2; also elsewhere on the board
CTL_PURGE: R28.1, SW17.2; also elsewhere on the board
CTL_RESET: SW3.3 (K), SW3.4 (A); also elsewhere on the board
CTL_RUN: SW1.3 (K), SW1.4 (A); also elsewhere on the board
CTL_SAFETY: R15.1, SW4.2; also elsewhere on the board
CTL_SEQUENCE_START: R16.1, SW5.2; also elsewhere on the board
CTL_SHIFT: R21.1, SW10.2; also elsewhere on the board
GND: R14.2, R15.2, R16.2, R17.2, R18.2, R19.2, R20.2, R21.2, R22.2, R23.2, R24.2, R25.2, R26.2, R27.2, R28.2, SW1.1, SW1.2, SW3.1, SW3.2; also elsewhere on the board

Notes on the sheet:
SEQUENCE START SWITCH A MOM +
OPEN SWITCH A ALT +
SHIFT SWITCH A ALT +
SAFETY SWITCH A ALT +
O2 SWITCH A ALT +
CLOSE SWITCH A ALT +
CONFIRM 3 SWITCH A ALT +
KILL SWITCH A MOM +
RESET SWITCH A MOM -
PURGE SWITCH A ALT +
RUN SWITCH A MOM +
FILL SWITCH A MOM +
IGNITOR SWITCH A ALT +
CONFIRM 2 SWITCH A ALT +
EMERGENCY STOP SWITCH A ALT +
CONFIRM 1 SWITCH A ALT +
DUMP SWITCH A ALT +

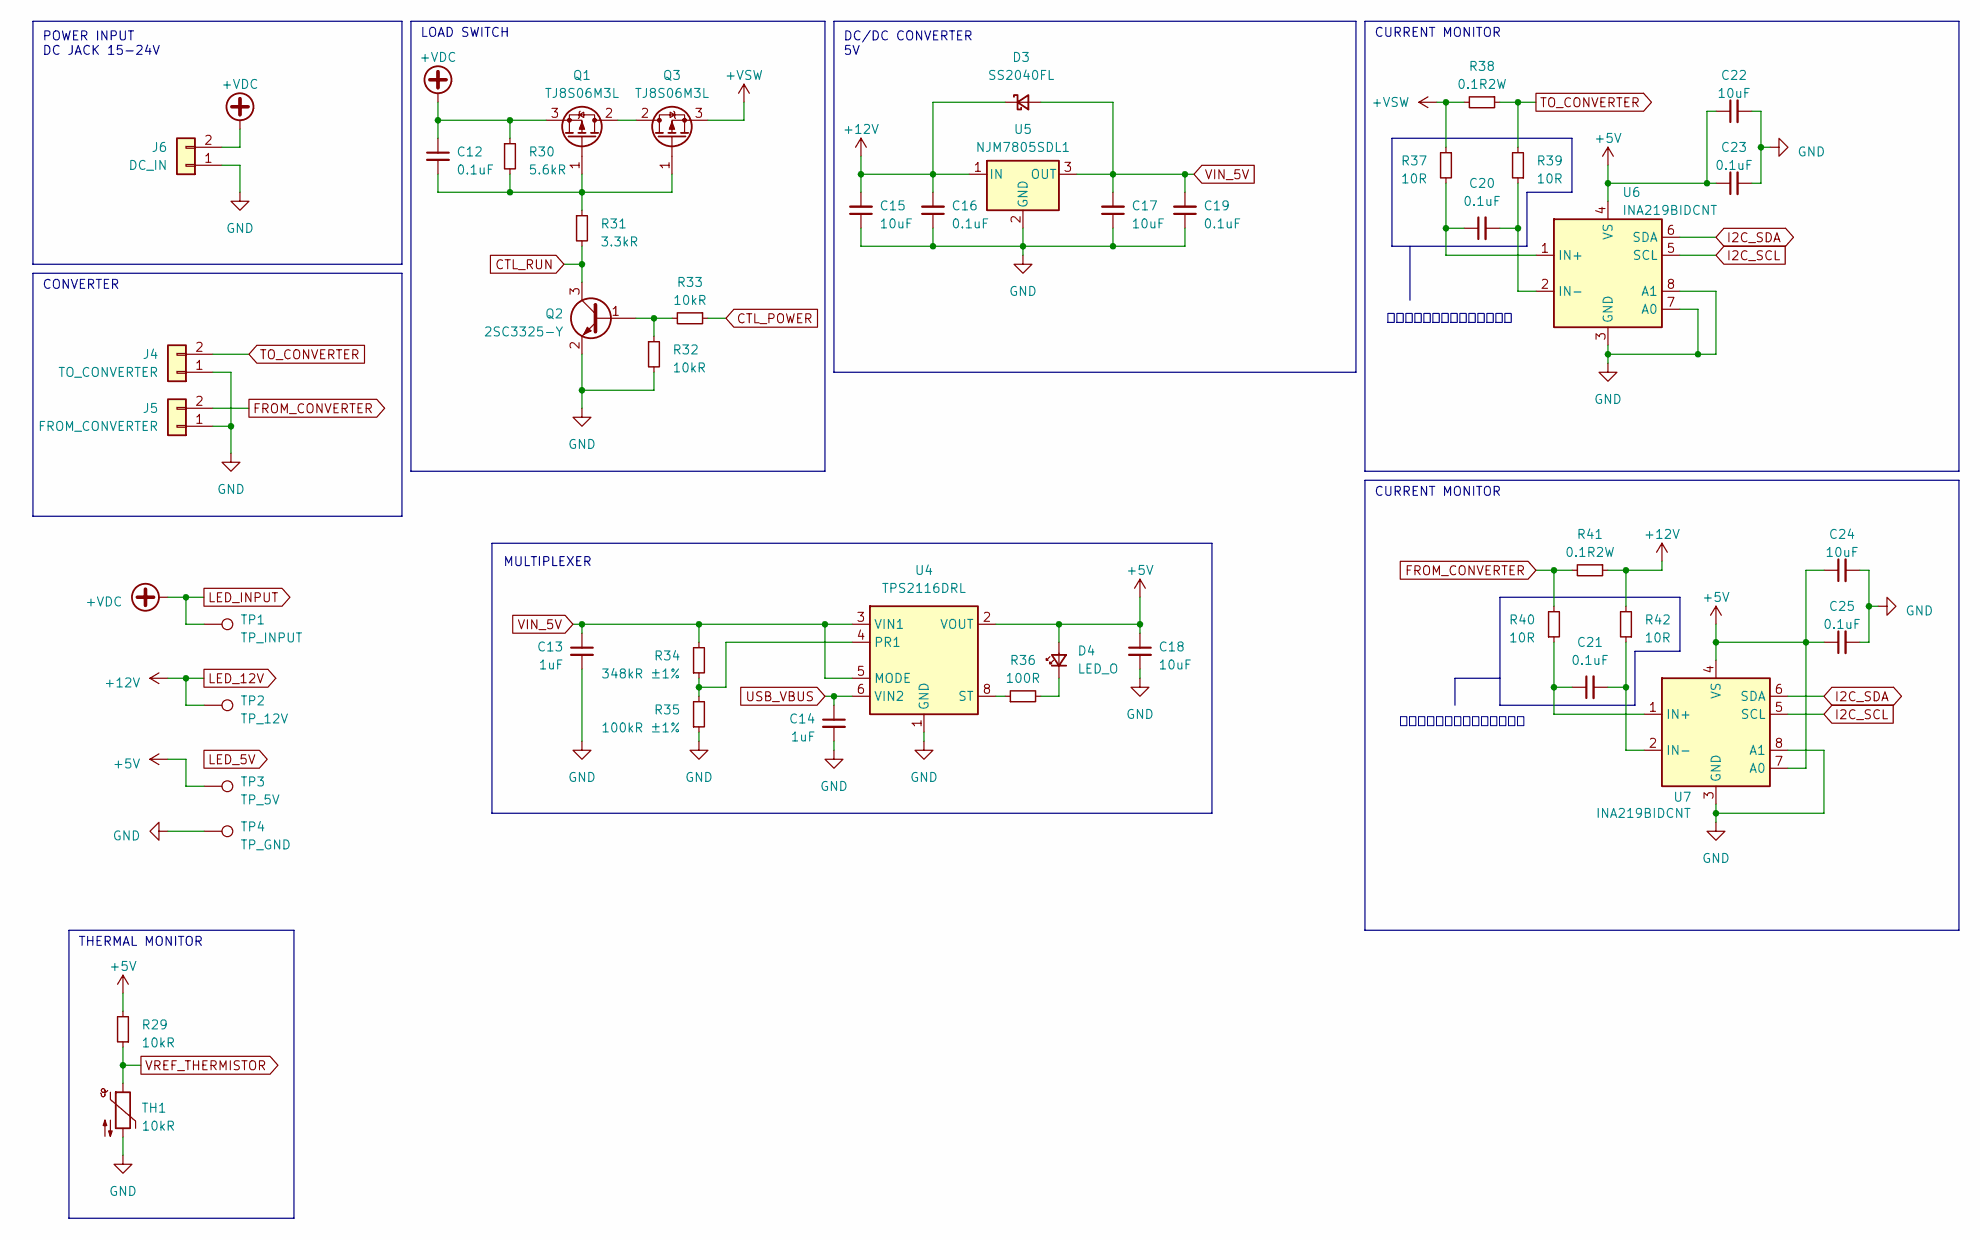
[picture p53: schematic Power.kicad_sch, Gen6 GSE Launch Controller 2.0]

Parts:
C12, C16, C19, C20, C21, C23, C25: 0.1uF; C_0603_1608Metric_Pad1.08x0.95mm_HandSolder
C13, C14: 1uF; C_0603_1608Metric_Pad1.08x0.95mm_HandSolder
C15, C17: 10uF; C_1206_3216Metric_Pad1.33x1.80mm_HandSolder
C18, C22, C24: 10uF; C_0805_2012Metric_Pad1.18x1.45mm_HandSolder
D3: SS2040FL; SOD-123FL_Handsolder
D4: LED_O; LED_0603_1608Metric_Pad1.05x0.95mm_HandSolder; Digikey_PN SML-D15DWT86CCT-ND
J4: TO_CONVERTER; TerminalBlock_WAGO_2601-3102_1x02_P3.50mm_Vertical; Digikey_PN 2946-2601-3102-ND
J5: FROM_CONVERTER; TerminalBlock_WAGO_2601-3102_1x02_P3.50mm_Vertical; Digikey_PN 2946-2601-3102-ND
J6: DC_IN; TerminalBlock_WAGO_2601-3102_1x02_P3.50mm_Vertical; Digikey_PN 2946-2601-3102-ND
Q1, Q3: TJ8S06M3L; TO-252-2
Q2: 2SC3325-Y; SC-59_Handsoldering
R29, R32, R33: 10kR; R_0603_1608Metric_Pad0.98x0.95mm_HandSolder; Digikey_PN 2019-RK73H1JTTD1002FCT-ND
R30: 5.6kR; R_0603_1608Metric_Pad0.98x0.95mm_HandSolder; Digikey_PN 2019-RK73H1JTTD5601FCT-ND
R31: 3.3kR; R_0603_1608Metric_Pad0.98x0.95mm_HandSolder; Digikey_PN 2019-RK73H1JTTD3301FCT-ND
R34: 348kR ±1%; R_0603_1608Metric_Pad0.98x0.95mm_HandSolder; Digikey_PN 2019-RK73H1JTTD3483FCT-ND
R35: 100kR ±1%; R_0603_1608Metric_Pad0.98x0.95mm_HandSolder; Digikey_PN 2019-RK73H1JTTD1003FCT-ND
R36: 100R; R_0603_1608Metric_Pad0.98x0.95mm_HandSolder; Digikey_PN 2019-RK73H1JTTD1000FCT-ND
R37, R39, R40, R42: 10R; R_0603_1608Metric_Pad0.98x0.95mm_HandSolder; Digikey_PN 2019-RK73H1JTTD10R0FCT-ND
R38, R41: 0.1R2W; R_2512_6332Metric_Pad1.40x3.35mm_HandSolder; Digikey_PN CRM2512-FX-R100ELFCT-ND
TH1: 10kR; R_0603_1608Metric_Pad0.98x0.95mm_HandSolder; Digikey_PN 2019-RK73H1JTTD1002FCT-ND
TP1: TP_INPUT; TestPoint_Keystone_5005-5009_Compact
TP2: TP_12V; TestPoint_Keystone_5005-5009_Compact
TP3: TP_5V; TestPoint_Keystone_5005-5009_Compact
TP4: TP_GND; TestPoint_Keystone_5005-5009_Compact
U4: TPS2116DRL; SOT-583-8; Digikey_PN 296-TPS2116DRLRCT-ND
U5: NJM7805SDL1; TO-252-2
U6, U7: INA219BIDCNT; SOT-23-8; Digikey_PN 296-27898-1-ND

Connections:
+VSW: Q3.3 (S), R37.1, R38.2
CONN_LED_5V: C18.1, C22.1, C23.1, C24.1, C25.1, D4.2 (A), R29.2, TP3.1, U4.2 (VOUT), U4.7 (VOUT), U6.4 (VS), U7.4 (VS), U7.7 (A0); also elsewhere on the board
CONN_LED_12V: C15.2, C16.2, D3.1 (K), R41.1, R42.2, TP2.1, U5.1 (IN); also elsewhere on the board
CONN_LED_INPUT: C12.1, J6.2, Q1.3 (S), R30.1, TP1.1; also elsewhere on the board
CTL_POWER: R33.1; also elsewhere on the board
CTL_RUN: Q2.3 (C), R31.2; also elsewhere on the board
FROM_CONVERTER: J5.2, R40.2, R41.2
GND: C13.2, C14.2, C15.1, C16.1, C17.1, C18.2, C19.1, C22.2, C23.2, C24.2, C25.2, J4.1, J5.1, J6.1, Q2.2 (E), R32.2, R35.1, TH1.2, TP4.1, U4.1 (GND), U5.2 (GND), U6.3 (GND), U6.7 (A0), U6.8 (A1), U7.3 (GND), U7.8 (A1); also elsewhere on the board
I2C_SCL: U6.5 (SCL), U7.5 (SCL); also elsewhere on the board
I2C_SDA: U6.6 (SDA), U7.6 (SDA); also elsewhere on the board
unnamed: D4.1 (K), R36.2
unnamed: Q1.2 (D), Q3.2 (D)
unnamed: C12.2, Q1.1 (G), Q3.1 (G), R30.2, R31.1
unnamed: Q2.1 (B), R32.1, R33.2
unnamed: R34.1, R35.2, U4.4 (PR1)
unnamed: R36.1, U4.8 (ST)
unnamed: C20.1, R37.2, U6.1 (IN+)
unnamed: C20.2, R39.1, U6.2 (IN-)
unnamed: C21.1, R40.1, U7.1 (IN+)
unnamed: C21.2, R42.1, U7.2 (IN-)
TO_CONVERTER: J4.2, R38.1, R39.2
USB_VBUS: C14.1, U4.6 (VIN2); also elsewhere on the board
VIN_5V: C13.1, C17.2, C19.2, D3.2 (A), R34.2, U4.3 (VIN1), U4.5 (MODE), U5.3 (OUT)
VREF_THERMISTOR: R29.1, TH1.1; also elsewhere on the board

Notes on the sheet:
ノイズなど，必要に応じて実装
MULTIPLEXER
THERMAL MONITOR
DC/DC CONVERTER 5V
CURRENT MONITOR
CONVERTER
LOAD SWITCH
POWER INPUT DC JACK 15-24V

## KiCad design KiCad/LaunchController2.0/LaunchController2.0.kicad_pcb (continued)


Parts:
J7: CONN_STATUS_PANEL; DF51A-14DP-2DS; Mouser_PN 798-DF51A14DP2DS50
J8: CONN_BOARD_3; DF51A-6DP-2DSA; Mouser_PN 798-DF51A-6DP-2DSA
J9: CONN_PANEL_BOARD_1; DF51A-18DP-2DS; Digikey_PN 26-DF51A-18DP-2DS(20)-ND
J10: CONN_PANEL_BOARD_2; DF51A-22DP-2DS; Digikey_PN 26-DF51A-22DP-2DS(20)-ND

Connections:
7SEG_CLK: J7.5; also elsewhere on the board
7SEG_DIO: J7.6; also elsewhere on the board
CONN_LED_5V: J7.10, J7.14, J8.6, J9.18, J10.22; also elsewhere on the board
CONN_LED_12V: J7.11; also elsewhere on the board
CONN_LED_CLOSE: J10.16; also elsewhere on the board
CONN_LED_COM: J7.9; also elsewhere on the board
CONN_LED_DUMP: J10.15; also elsewhere on the board
CONN_LED_EMERGENCY: J10.21; also elsewhere on the board
CONN_LED_ERROR: J7.3; also elsewhere on the board
CONN_LED_FILL: J10.13; also elsewhere on the board
CONN_LED_IGNITOR: J10.12; also elsewhere on the board
CONN_LED_INPUT: J7.12; also elsewhere on the board
CONN_LED_LOW_VOLTAGE: J7.2; also elsewhere on the board
CONN_LED_O2: J10.17; also elsewhere on the board
CONN_LED_OPEN: J10.14; also elsewhere on the board
CONN_LED_PURGE: J10.18; also elsewhere on the board
CONN_LED_RS485_ACCESS: J7.4; also elsewhere on the board
CONN_LED_SAFTEY: J10.20; also elsewhere on the board
CONN_LED_SEQUENCE: J10.19; also elsewhere on the board
CONN_LED_SHIFT: J10.11; also elsewhere on the board
CONN_LED_TASK: J7.8; also elsewhere on the board
CONN_LED_USB_ACCESS: J7.7; also elsewhere on the board
CTL_CLOSE: J9.11; also elsewhere on the board
CTL_CONFIRM_1: J8.2; also elsewhere on the board
CTL_CONFIRM_2: J8.3; also elsewhere on the board
CTL_CONFIRM_3: J8.4; also elsewhere on the board
CTL_DUMP: J9.13; also elsewhere on the board
CTL_EMERGENCY_STOP: J9.3; also elsewhere on the board
CTL_FILL: J9.9; also elsewhere on the board
CTL_IGNITOR: J9.5; also elsewhere on the board
CTL_KILL: J9.8; also elsewhere on the board
CTL_O2: J9.17; also elsewhere on the board
CTL_OPEN: J9.7; also elsewhere on the board
CTL_PURGE: J9.15; also elsewhere on the board
CTL_RESET: J7.13; also elsewhere on the board
CTL_RUN: J9.10; also elsewhere on the board
CTL_SAFETY: J9.2; also elsewhere on the board
CTL_SEQUENCE_START: J9.4; also elsewhere on the board
CTL_SHIFT: J9.6; also elsewhere on the board
GND: J7.1, J9.1, J10.1; also elsewhere on the board


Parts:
D6, D13, D15: LED_G; LED_0603_1608Metric_Pad1.05x0.95mm_HandSolder; Digikey_PN SML-D12P8WT86CCT-ND
D7, D8, D9, D11, D16, D17, D18, D19, D20, D21, D22, D23, D24, D25, D26: LED_O; LED_0603_1608Metric_Pad1.05x0.95mm_HandSolder; Digikey_PN SML-D15DWT86CCT-ND
D10: LED_B; LED_0603_1608Metric_Pad1.05x0.95mm_HandSolder; Digikey_PN SMLD12BN1WT86CT-ND
D12, D14: LED_R; LED_0603_1608Metric_Pad1.05x0.95mm_HandSolder; Digikey_PN SML-D12U8WT86CCT-ND
R46, R48, R50, R51, R52, R53, R54, R55, R56, R57, R58, R59, R60, R61, R62, R63, R64, R65, R66: 1kR; R_0603_1608Metric_Pad0.98x0.95mm_HandSolder; Digikey_PN 2019-RK73H1JTTD1001FCT-ND
R47, R49: 5.1kR; R_0603_1608Metric_Pad0.98x0.95mm_HandSolder; Digikey_PN 2019-RK73H1JTTD5101FCT-ND

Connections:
CONN_LED_5V: D6.2 (A), D8.2 (A), R51.1; also elsewhere on the board
CONN_LED_12V: R49.1; also elsewhere on the board
CONN_LED_CLOSE: R64.1; also elsewhere on the board
CONN_LED_COM: R53.1; also elsewhere on the board
CONN_LED_DUMP: R63.1; also elsewhere on the board
CONN_LED_EMERGENCY: R58.1; also elsewhere on the board
CONN_LED_ERROR: R52.1; also elsewhere on the board
CONN_LED_FILL: R61.1; also elsewhere on the board
CONN_LED_IGNITOR: R60.1; also elsewhere on the board
CONN_LED_INPUT: R47.1; also elsewhere on the board
CONN_LED_LOW_VOLTAGE: R54.1; also elsewhere on the board
CONN_LED_O2: R65.1; also elsewhere on the board
CONN_LED_OPEN: R62.1; also elsewhere on the board
CONN_LED_PURGE: R66.1; also elsewhere on the board
CONN_LED_RS485_ACCESS: R50.1; also elsewhere on the board
CONN_LED_SAFTEY: R57.1; also elsewhere on the board
CONN_LED_SEQUENCE: R56.1; also elsewhere on the board
CONN_LED_SHIFT: R59.1; also elsewhere on the board
CONN_LED_TASK: R55.1; also elsewhere on the board
CONN_LED_USB_ACCESS: R46.2; also elsewhere on the board
GND: D7.1 (K), D9.1 (K), D10.1 (K), D11.1 (K), D12.1 (K), D13.1 (K), D14.1 (K), D15.1 (K), D16.1 (K), D17.1 (K), D18.1 (K), D19.1 (K), D20.1 (K), D21.1 (K), D22.1 (K), D23.1 (K), D24.1 (K), D25.1 (K), D26.1 (K); also elsewhere on the board
LED_USB_TXLED: R48.2; also elsewhere on the board
unnamed: D6.1 (K), R46.1
unnamed: D7.2 (A), R47.2
unnamed: D8.1 (K), R48.1
unnamed: D9.2 (A), R49.2
unnamed: D10.2 (A), R50.2
unnamed: D11.2 (A), R51.2
unnamed: D12.2 (A), R52.2
unnamed: D13.2 (A), R53.2
unnamed: D14.2 (A), R54.2
unnamed: D15.2 (A), R55.2
unnamed: D16.2 (A), R56.2
unnamed: D17.2 (A), R57.2
unnamed: D18.2 (A), R58.2
unnamed: D19.2 (A), R59.2
unnamed: D20.2 (A), R60.2
unnamed: D21.2 (A), R61.2
unnamed: D22.2 (A), R62.2
unnamed: D23.2 (A), R63.2
unnamed: D24.2 (A), R64.2
unnamed: D25.2 (A), R65.2
unnamed: D26.2 (A), R66.2

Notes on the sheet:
LED_PURGE
LED_O2
LED_SHIFT
LED_DUMP
LED_RS485_ACCESS
LED_EMERGENCY
LED_IGNITOR
LED_ERROR
LED_LOW_VOLTAGE
LED_CLOSE
LED_INPUT
LED_5V
LED_12V
LED_SEQUENCE
LED_TASK
LED_COM
LED_FILL
LED_OPEN
LED_SAFETY
LED_USB_ACCESS

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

Board: 2 copper layers, 150.0 x 100.0 mm, 184 parts (0 on the bottom side), 132 nets.

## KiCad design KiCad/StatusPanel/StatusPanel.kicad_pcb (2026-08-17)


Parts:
C1, C2, C3: 0.1uF; C_0603_1608Metric_Pad1.08x0.95mm_HandSolder
C4: 100uF; C_Elec_6.3x7.7
J1: CONN; DF11CZ-16DP-2V
J2: CONN_RESET_CTL; 1p
J3: CONN_RESET_GND; 1p
J4: CONN_USB_5V; 1p
J5: CONN_USB_CTL; 1p
J6: CONN_INPUT_CTL; 1p
J7: CONN_INPUT_GND; 1p
J8: CONN_RS485_CTL; 1p
J9: CONN_RS485_GND; 1p
J10: CONN_12V_CTL; 1p
J11: CONN_12V_GND; 1p
J12: CONN_TASK_CTL; 1p
J13: CONN_TASK_GND; 1p
J14: CONN_5V_CTL; 1p
J15: CONN_5V_GND; 1p
J16: CONN_COM_CTL; 1p
J17: CONN_COM_GND; 1p
J18: CONN_LOW_CTL; 1p
J19: CONN_LOW_GND; 1p
J20: CONN_ERROR_CTL; 1p
J21: CONN_ERROR_GND; 1p
R1, R2, R3, R4, R5, R6, R7, R8, R9: 270R; R_0603_1608Metric_Pad0.98x0.95mm_HandSolder
U1: 2281SB; Sx39-1xxxxx
U2: TM1637; SOP-20_7.5x12.8mm_P1.27mm

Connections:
5V: J1.11, R6.1
12V: J1.5, R4.1
+5V: C1.2, C4.1, J1.6, J4.1, U2.16 (VDD)
CLK: C2.2, J1.10, U2.18 (CLK)
COM: J1.13, R7.1
DIO: C3.2, J1.12, U2.17 (DIO)
ERROR: J1.16, R9.1
GND: C1.1, C2.1, C3.1, C4.2, J1.8, J1.9, J1.14, J3.1, J7.1, J9.1, J11.1, J13.1, J15.1, J17.1, J19.1, J21.1, U2.1 (GND)
INPUT: J1.1, R2.1
LOW: J1.15, R8.1
unnamed: J5.1, R1.1
unnamed: J6.1, R2.2
unnamed: J8.1, R3.2
unnamed: J10.1, R4.2
unnamed: J12.1, R5.2
unnamed: J14.1, R6.2
unnamed: J16.1, R7.2
unnamed: J18.1, R8.2
unnamed: J20.1, R9.2
unnamed: U1.7 (A), U2.2 (SEG1/KS1)
unnamed: U1.8 (B), U2.3 (SEG2/KS2)
unnamed: U1.3 (C), U2.4 (SEG3/KS3)
unnamed: U1.2 (D), U2.5 (SEG4/KS4)
unnamed: U1.9 (DEG1), U2.14 (GRID2)
unnamed: U1.6 (DEG2), U2.15 (GRID1)
unnamed: U1.5 (DP), U2.9 (SEG8/KS8)
unnamed: U1.1 (E), U2.6 (SEG5/KS5)
unnamed: U1.10 (F), U2.7 (SEG6/KS6)
unnamed: U1.4 (G), U2.8 (SEG7/KS7)
RESET: J1.4, J2.1
RS485: J1.3, R3.1
TASK: J1.7, R5.1
USB: J1.2, R1.2



Board: 2 copper layers, 121.0 x 92.0 mm, 36 parts (35 on the bottom side), 33 nets.

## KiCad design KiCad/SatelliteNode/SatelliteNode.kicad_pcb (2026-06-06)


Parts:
C1, C3, C4: 0.1uF; C_0603_1608Metric
D1: BZX55C3V3; D_DO-35_SOD27_P7.62mm_Horizontal
D2: RB160M-30TR; SOD-123FL_Handsolder
F1: MF-R050; Fuse_Bourns_MF-RG300
H1, H2, H3: MountingHole; MountingHole_3.2mm_M3
J1: 12V_Connector; DF51A-2P-2DSA
J2: Isolated_RS485; StrawberryLinux_ADM2582
J3, J4, J5, J6, J7, J8: Conn_01x04; DF51A-4P-2DSA
R1, R2: 4.7kR; R_0603_1608Metric
R3, R5: 10kR 1%; R_0603_1608Metric
R4, R6, R7, R8, R9, R10: 10kR; R_0603_1608Metric
U2: SSD1306
U3: XIAO-ESP32-C6; XIAO-ESP32-C6-DIP
U4: MCP23017_SP; DIP-28_W7.62mm
U5: 74HC14; DIP-14_W7.62mm_LongPads
U6: BP5293-50; TO-220F-3_Vertical

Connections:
5V_ADC: C1.2, D1.1 (K), R3.2, R5.2, U3.2 (GPIO1/A1/D1)
+3.3V: C3.1, C4.1, J2.10, J3.2, J4.2, J5.2, J6.2, J7.2, J8.2, R1.1, R2.1, R4.1, R6.1, R7.1, R8.1, R9.1, R10.1, U2.2 (VCC), U3.12 (3V3), U4.9 (VDD), U4.18 (~RESET), U5.14 (VCC)
+5V: D2.2 (A), R3.1, U6.3 (VOUT)
+12V: F1.1, J1.2
GND: C1.1, C3.2, C4.2, D1.2 (A), J1.1, J2.9, J3.1, J4.1, J5.1, J6.1, J7.1, J8.1, R5.1, U2.1 (GND), U3.13 (GND), U4.10 (VSS), U4.15 (A0), U4.16 (A1), U4.17 (A2), U5.7 (GND), U6.2 (GND)
I2C_SCL: R2.2, U2.3 (SCL), U3.6 (GPIO23/D5/SCL), U4.12 (SCK)
I2C_SDA: R1.2, U2.4 (SDA), U3.5 (GPIO22/D4/SDA), U4.13 (SDA)
LED_CTL_0: J3.4, U4.1 (GPB0)
LED_CTL_1: J4.4, U4.2 (GPB1)
LED_CTL_2: J5.4, U4.3 (GPB2)
LED_CTL_3: J6.4, U4.4 (GPB3)
LED_CTL_4: J7.4, U4.5 (GPB4)
LED_CTL_5: J8.4, U4.6 (GPB5)
unnamed: D2.1 (K), U3.14 (VBUS)
unnamed: J3.3, R4.2, U5.1
unnamed: J4.3, R6.2, U5.3
unnamed: J5.3, R7.2, U5.5
unnamed: J6.3, R8.2, U5.9
unnamed: J7.3, R9.2, U5.11
unnamed: J8.3, R10.2, U5.13
unnamed: F1.2, U6.1 (VIN)
RS485_DI: J2.5, U3.7 (GPIO16/D6/TX)
RS485_RO: J2.3, U3.8 (GPIO17/D7/RX)
RS485_~RE_DE: J2.15, J2.17, U3.1 (GPIO0/A0/D0)
SPI_MISO: U3.10 (GPIO20/D9/MISO)
SPI_MOSI: U3.11 (GPIO18/D10/MOSI)
SPI_SCK: U3.9 (GPIO19/D8/SCK)
Switch_Out_0: U4.23 (GPA2), U5.2
Switch_Out_1: U4.22 (GPA1), U5.4
Switch_Out_2: U4.21 (GPA0), U5.6
Switch_Out_3: U4.26 (GPA5), U5.8
Switch_Out_4: U4.25 (GPA4), U5.10
Switch_Out_5: U4.24 (GPA3), U5.12


Board: 2 copper layers, 80.0 x 60.0 mm, 32 parts (0 on the bottom side), 30 nets.

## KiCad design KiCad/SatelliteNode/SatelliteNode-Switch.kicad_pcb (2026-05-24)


Board: 2 copper layers, 30.0 x 30.0 mm, 11 parts (0 on the bottom side), 7 nets.

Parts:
C1: 0.1uF; C_0603_1608Metric
D1: GREEN; LED_0603_1608Metric
D2: RED; LED_0603_1608Metric
H3: MountingHole_Pad; TestPoint_THTPad_D3.0mm_Drill1.5mm
H4: MountingHole_Pad; TestPoint_THTPad_3.0x3.0mm_Drill1.5mm
J1: DF51A-4P-2DS
M3, M3#2: MountingHole; MountingHole_3.2mm_M3
Q1: DTC123EU3; SOT-323_SC-70
R1, R2: 330R; R_0603_1608Metric

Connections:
+3.3V: C1.1, J1.2, R1.1, R2.1
GND: C1.2, H4.1, J1.1, Q1.2 (E)
LED_CTRL: D1.1 (K), J1.4, Q1.1 (B)
unnamed: D1.2 (A), R1.2
unnamed: D2.2 (A), R2.2
unnamed: D2.1 (K), Q1.3 (C)
SW_OUT: H3.1, J1.3

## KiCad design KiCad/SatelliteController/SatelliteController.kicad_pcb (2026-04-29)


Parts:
C1, C2: 15pF; C_0603_1608Metric_Pad1.08x0.95mm_HandSolder
C3, C4, C5, C6, C7, C8, C9, C10: 0.1uF; C_0603_1608Metric_Pad1.08x0.95mm_HandSolder
D1: GS1010FL; D_SOD-123F
D2: LED_O; LED_0603_1608Metric_Pad1.05x0.95mm_HandSolder
D3, D4: SMAJ45A; D_SMA_Handsoldering
F1: MF-NSMF050; Fuse_1206_3216Metric_Pad1.42x1.75mm_HandSolder
J1: CONN_ICSP; PinSocket_1x06_P2.54mm_Vertical
J2: CONN_USB; TB401-1-4-E
J3: USB_B_Micro; USB_Micro-B_Wuerth_629105150521
L1: 10uH; L_1210_3225Metric_Pad1.42x2.65mm_HandSolder
R1, R5, R7, R8: 10kR; R_0603_1608Metric_Pad0.98x0.95mm_HandSolder
R2: 1MR; R_0603_1608Metric_Pad0.98x0.95mm_HandSolder
R3, R4, R6, R11: 1kR; R_0603_1608Metric_Pad0.98x0.95mm_HandSolder
R9, R10: 22R; R_0603_1608Metric_Pad0.98x0.95mm_HandSolder
U1: ATMEGA2560-16AUR; TQFP-100_14x14mm_P0.5mm
U2: FT232RL; SSOP-28_5.3x10.2mm_P0.65mm
Y1: HUSG-16.000-20; Crystal_HC49-U_Vertical

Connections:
7SEG_CLK: U1.89 (PK0); also elsewhere on the board
7SEG_DIO: U1.88 (PK1); also elsewhere on the board
CONN_LED_5V: C4.1, C5.1, C6.1, C9.2, D1.1 (K), F1.2, J1.2, L1.2, R1.1, R5.1, R7.1, R8.1, U1.10 (VCC), U1.31 (VCC), U1.61 (VCC), U1.80 (VCC), U2.4 (VCCIO), U2.20 (VCC); also elsewhere on the board
CONN_LED_CHECK: U1.28 (PG3); also elsewhere on the board
CONN_LED_COM: U1.84 (PK5); also elsewhere on the board
CONN_LED_ERROR: U1.83 (PK6); also elsewhere on the board
CONN_LED_LOW_VOLTAGE: U1.82 (PK7); also elsewhere on the board
CONN_LED_RS485_ACCESS: U1.74 (PA4); also elsewhere on the board
CONN_LED_SAFTEY: U1.27 (PH7); also elsewhere on the board
CONN_LED_TASK: U1.85 (PK4); also elsewhere on the board
CONN_LED_USB_ACCESS: U2.22 (CBUS1), U2.23 (CBUS0); also elsewhere on the board
CS_ADC: R5.2, U1.57 (PC4); also elsewhere on the board
CTL_CLOSE: U1.51 (PG0); also elsewhere on the board
CTL_DUMP: U1.52 (PG1); also elsewhere on the board
CTL_FB_O2: U1.54 (PC1)
CTL_FILL: U1.48 (PD5); also elsewhere on the board
CTL_IGNITOR: U1.50 (PD7); also elsewhere on the board
CTL_KILL: U1.64 (PJ1); also elsewhere on the board
CTL_O2: U1.56 (PC3); also elsewhere on the board
CTL_OPEN: U1.49 (PD6); also elsewhere on the board
CTL_POWER: U1.92 (PF5); also elsewhere on the board
CTL_PURGE: U1.53 (PC0); also elsewhere on the board
CTL_RESET: C10.2, D1.2 (A), J1.5, R1.2, U1.30 (~RESET); also elsewhere on the board
CTL_RS485_DERE: U1.76 (PA2); also elsewhere on the board
CTL_SAFETY: U1.55 (PC2); also elsewhere on the board
CTL_SHIFT: U1.47 (PD4); also elsewhere on the board
FLIGHT_MODE: U1.15 (PH3); also elsewhere on the board
GND: C1.1, C2.1, C3.1, C4.2, C5.2, C6.2, C7.2, C8.1, C9.1, D3.2 (A2), D4.2 (A2), J1.6, J2.1, J3.5 (GND), J3.6 (Shield), R6.2, R11.2, U1.11 (GND), U1.32 (GND), U1.62 (GND), U1.81 (GND), U1.99 (GND), U2.7 (GND), U2.18 (GND), U2.21 (GND), U2.25 (AGND), U2.26 (TEST); also elsewhere on the board
I2C_SCL: R7.2, U1.43 (PD0); also elsewhere on the board
I2C_SDA: R8.2, U1.44 (PD1); also elsewhere on the board
LED_PURGE: U1.25 (PB6)
unnamed: D2.2 (A), U1.26 (PB7)
unnamed: D2.1 (K), R6.1
unnamed: C3.2, U1.98 (AREF)
unnamed: C7.1, L1.1, U1.100 (AVCC)
unnamed: R3.1, U1.2 (PE0)
unnamed: R4.2, U1.3 (PE1)
unnamed: C1.2, R2.1, U1.34 (XTAL1), Y1.2
unnamed: C2.2, R2.2, U1.33 (XTAL2), Y1.1
unnamed: C8.2, U2.17 (3V3OUT)
unnamed: C10.1, R11.1, U2.2 (DTR)
unnamed: R9.2, U2.15 (USBD+)
unnamed: R10.1, U2.16 (USBD-)
SPI_MISO: J1.1, U1.22 (PB3); also elsewhere on the board
SPI_MOSI: J1.4, U1.21 (PB2); also elsewhere on the board
SPI_SCK: J1.3, U1.20 (PB1); also elsewhere on the board
SW_CHECK: U1.29 (PG4); also elsewhere on the board
UART0_RX: R3.2, U2.1 (TXD)
UART0_TX: R4.1, U2.5 (RXD)
UART1_RX: U1.45 (PD2); also elsewhere on the board
UART1_TX: U1.46 (PD3); also elsewhere on the board
USB_D+: D3.1 (A1), J2.2, J3.3 (D+), R9.1
USB_D-: D4.1 (A1), J2.3, J3.2 (D-), R10.2
USB_VBUS: F1.1, J2.4, J3.1 (VBUS)
VALVE_MODE: U1.14 (PH2); also elsewhere on the board
VREF_N2O_PRESS: U1.87 (PK2); also elsewhere on the board
VREF_THERMISTOR: U1.93 (PF4); also elsewhere on the board

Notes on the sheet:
CONNECTION ICSP
CONNECTION USB
USB-Serial


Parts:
C18: 0.1uF; C_0603_1608Metric_Pad1.08x0.95mm_HandSolder
D27, D28, D29, D30, D31, D32, D33, D34, D35: GS1010FL; D_SOD-123F
J12: RELAY_POWER; TB411-2-2-E-1
J13: IGNITOR; TB411-2-2-E-1
J14: CONN_SORENOID_VALVE; DF51A-8DP-2DS
Q4, Q5, Q6, Q7, Q8, Q9, Q10, Q11, Q12, Q13: AO3400A; SOT-23
R49, R51, R55, R57, R59, R67, R69, R75, R77, R79: 120R; R_0603_1608Metric_Pad0.98x0.95mm_HandSolder
R50, R52, R56, R58, R60, R68, R70, R76, R78, R80: 10kR; R_0603_1608Metric_Pad0.98x0.95mm_HandSolder
R53, R61, R63, R65, R71, R73, R81, R83: 56kR; R_0603_1608Metric_Pad0.98x0.95mm_HandSolder
R54, R62, R64, R66, R72, R74, R82, R84: 33kR; R_0603_1608Metric_Pad0.98x0.95mm_HandSolder
U9: MCP3208; DIP-16_W7.62mm

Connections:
CONN_LED_5V: C18.2, U9.15 (VREF), U9.16 (VDD); also elsewhere on the board
CONN_LED_12V: D27.1 (K), D28.1 (K), D29.1 (K), D30.1 (K), D31.1 (K), D32.1 (K), D33.1 (K), D34.1 (K), D35.1 (K), J12.1, J12.2, J13.2; also elsewhere on the board
CONN_LED_CHECK: R75.1; also elsewhere on the board
CONN_LED_SAFTEY: R49.1; also elsewhere on the board
CS_ADC: U9.10 (nCS); also elsewhere on the board
CTL_CLOSE: R51.1; also elsewhere on the board
CTL_DUMP: R77.1; also elsewhere on the board
CTL_FILL: R67.1; also elsewhere on the board
CTL_IGNITOR: R69.1; also elsewhere on the board
CTL_O2: R57.1; also elsewhere on the board
CTL_OPEN: R79.1; also elsewhere on the board
CTL_PURGE: R59.1; also elsewhere on the board
CTL_SHIFT: R55.1; also elsewhere on the board
GND: C18.1, Q4.2 (S), R50.1, R52.1, R54.1, R56.1, R58.1, R60.1, R62.1, R64.1, R66.1, R68.1, R70.1, R72.1, R74.1, R76.1, R78.1, R80.1, R82.1, R84.1, U9.9 (DGND), U9.14 (AGND); also elsewhere on the board
unnamed: Q4.1 (G), R49.2, R50.2
unnamed: Q5.1 (G), R51.2, R52.2
unnamed: Q6.1 (G), R55.2, R56.2
unnamed: Q7.1 (G), R57.2, R58.2
unnamed: Q8.1 (G), R59.2, R60.2
unnamed: Q9.1 (G), R67.2, R68.2
unnamed: Q10.1 (G), R69.2, R70.2
unnamed: Q11.1 (G), R75.2, R76.2
unnamed: Q12.1 (G), R77.2, R78.2
unnamed: Q13.1 (G), R79.2, R80.2
SAFETY_12V: Q4.3 (D), Q5.2 (S), Q6.2 (S), Q7.2 (S), Q8.2 (S), Q9.2 (S), Q10.2 (S), Q11.2 (S), Q12.2 (S), Q13.2 (S)
SPI_MISO: U9.12 (DOUT); also elsewhere on the board
SPI_MOSI: U9.11 (DIN); also elsewhere on the board
SPI_SCK: U9.13 (CLK); also elsewhere on the board
SV_CHECK: D33.2 (A), J14.6, Q11.3 (D)
SV_CLOSE: D27.2 (A), J14.7, Q5.3 (D), R53.2
SV_DUMP: D34.2 (A), J14.1, Q12.3 (D), R81.2
SV_FILL: D31.2 (A), J14.2, Q9.3 (D), R71.2
SV_IGNITOR: D32.2 (A), J13.1, Q10.3 (D), R73.2
SV_O2: D29.2 (A), J14.3, Q7.3 (D), R63.2
SV_OPEN: D35.2 (A), J14.5, Q13.3 (D), R83.2
SV_PURGE: D30.2 (A), J14.8, Q8.3 (D), R65.2
SV_SHIFT: D28.2 (A), J14.4, Q6.3 (D), R61.2
VREF_CLOSE: R53.1, R54.2, U9.6 (CH5)
VREF_DUMP: R81.1, R82.2, U9.3 (CH2)
VREF_FILL: R71.1, R72.2, U9.2 (CH1)
VREF_IGNITOR: R73.1, R74.2, U9.8 (CH7)
VREF_O2: R63.1, R64.2, U9.4 (CH3)
VREF_OPEN: R83.1, R84.2, U9.7 (CH6)
VREF_PURGE: R65.1, R66.2, U9.5 (CH4)
VREF_SHIFT: R61.1, R62.2, U9.1 (CH0)


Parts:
J9: CONN_RS485; TB401-1-4-E
J10: CONN_N2O_PRESS; TB401-1-4-E
J11: CONN_UMBILICAL; TB401-1-4-E
R23: 120R; R_0603_1608Metric_Pad0.98x0.95mm_HandSolder
R24: 240R; R_0603_1608Metric_Pad0.98x0.95mm_HandSolder
R25, R26: 300R; R_0603_1608Metric_Pad0.98x0.95mm_HandSolder
U6: LTC485CN8#PBF; DIP-8_W7.62mm
U7, U8: TLP785F; DIP-4_W10.16mm

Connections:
CONN_LED_5V: U6.8 (VCC); also elsewhere on the board
CONN_LED_12V: J10.4; also elsewhere on the board
CTL_RS485_DERE: U6.2 (~RE), U6.3 (DE); also elsewhere on the board
FLIGHT_MODE: R25.1; also elsewhere on the board
GND: J9.1, J9.4, J10.1, J10.3, R24.2, U6.5 (GND), U7.2, U8.2; also elsewhere on the board
unnamed: J9.2, R23.2, U6.6 (A)
unnamed: J9.3, R23.1, U6.7 (B)
unnamed: J11.1, U8.3
unnamed: J11.2, U8.4
unnamed: J11.3, U7.4
unnamed: J11.4, U7.3
unnamed: R25.2, U7.1
unnamed: R26.2, U8.1
UART1_RX: U6.1 (RO); also elsewhere on the board
UART1_TX: U6.4 (DI); also elsewhere on the board
VALVE_MODE: R26.1; also elsewhere on the board
VREF_N2O_PRESS: J10.2, R24.1; also elsewhere on the board

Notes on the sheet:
N2O PRESS
UMBILICAL
RS485


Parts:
R46, R47, R48: 1kR; R_0603_1608Metric_Pad0.98x0.95mm_HandSolder
SW1, SW2, SW4: SW_Push; TVAF06-A020B-R
SW3: SW_Push; PinHeader_1x02_P2.54mm_Vertical

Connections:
CONN_LED_5V: R46.2, R48.2, SW2.1; also elsewhere on the board
CTL_KILL: R47.1, SW2.2; also elsewhere on the board
CTL_RESET: SW4.2; also elsewhere on the board
CTL_RUN: SW1.2; also elsewhere on the board
CTL_SAFETY: R48.1, SW3.2; also elsewhere on the board
GND: R47.2, SW1.1, SW3.1, SW4.1; also elsewhere on the board
SW_CHECK: R46.1; also elsewhere on the board

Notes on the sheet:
KILL SWITCH A MOM +
SAFETY SWITCH A ALT -
CHECK SWITCH A ALT -
RESET SWITCH A MOM -
RUN SWITCH A MOM +


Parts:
C11, C13, C15, C16, C17: 0.1uF; C_0603_1608Metric_Pad1.08x0.95mm_HandSolder
C12, C14: 10uF; C_1206_3216Metric_Pad1.33x1.80mm_HandSolder
D5: GS1010FL; D_SOD-123F
D6, D7: SS2040FL; D_SOD-123F
J4: TO_CONVERTER; TB411-2-2-E-1
J5: FROM_CONVERTER; TB411-2-2-E-1
J6: DC_IN; TB411-2-2-E-1
Q1, Q3: TJ8S06M3L; TO-252-2
Q2: 2SC3325-Y; SC-59_Handsoldering
R12: 5.6kR; R_0603_1608Metric_Pad0.98x0.95mm_HandSolder
R13: 3.3kR; R_0603_1608Metric_Pad0.98x0.95mm_HandSolder
R14, R15, R16, R19, R20, R21, R22: 10kR; R_0603_1608Metric_Pad0.98x0.95mm_HandSolder
R17, R18: 0.1R2W; R_2816_7142Metric_Pad3.20x4.45mm_HandSolder
TH1: 10kR; R_0603_1608Metric_Pad0.98x0.95mm_HandSolder
TP1: TP_INPUT; TestPoint_THTPad_D2.5mm_Drill1.2mm
TP2: TP_12V; TestPoint_THTPad_D2.5mm_Drill1.2mm
TP3: TP_5V; TestPoint_THTPad_D2.5mm_Drill1.2mm
TP4: TP_GND; TestPoint_THTPad_D2.5mm_Drill1.2mm
U3: NJM7805SDL1; TO-252-2
U4, U5: INA219BIDCNT; SOT-23-8

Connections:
+VSW: Q3.3 (S), R17.2, U4.1 (IN+)
CONN_LED_5V: C16.1, C17.1, D7.1 (K), R16.2, R21.1, TP3.1, U4.4 (VS), U5.4 (VS), U5.7 (A0); also elsewhere on the board
CONN_LED_12V: C12.2, C13.2, D5.1 (K), R18.1, TP2.1, U3.1 (IN), U5.2 (IN-); also elsewhere on the board
CONN_LED_INPUT: C11.1, J6.2, Q1.3 (S), R12.1, TP1.1; also elsewhere on the board
CTL_POWER: R15.1; also elsewhere on the board
CTL_RUN: Q2.3 (C), R13.2; also elsewhere on the board
FROM_CONVERTER: J5.2, R18.2, U5.1 (IN+)
GND: C16.2, C17.2, D6.1 (K), J4.1, J5.1, J6.1, Q2.2 (E), R14.2, R19.2, R20.1, R21.2, R22.1, TH1.2, TP4.1, U4.3 (GND), U5.3 (GND); also elsewhere on the board
I2C_SCL: U4.5 (SCL), U5.5 (SCL); also elsewhere on the board
I2C_SDA: U4.6 (SDA), U5.6 (SDA); also elsewhere on the board
unnamed: C14.2, C15.2, D5.2 (A), D7.2 (A), U3.3 (OUT)
unnamed: C12.1, C13.1, C14.1, C15.1, D6.2 (A), U3.2 (GND)
unnamed: Q1.2 (D), Q3.2 (D)
unnamed: C11.2, Q1.1 (G), Q3.1 (G), R12.2, R13.1
unnamed: Q2.1 (B), R14.1, R15.2
unnamed: R19.1, U4.7 (A0)
unnamed: R20.2, U4.8 (A1)
unnamed: R22.2, U5.8 (A1)
TO_CONVERTER: J4.2, R17.1, U4.2 (IN-)
VREF_THERMISTOR: R16.1, TH1.1; also elsewhere on the board

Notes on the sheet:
CURRENT MONITOR
POWER INPUT DC JACK 15-24V
DC/DC CONVERTER 5V
CONVERTER
THERMAL MONITOR
LOAD SWITCH


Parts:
J7: CONN_STATUS_PANEL; DF51A-14DP-2DS
J8: CONN_PANEL_BAORD_2; DF51A-22DP-2DS

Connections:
7SEG_CLK: J7.5; also elsewhere on the board
7SEG_DIO: J7.6; also elsewhere on the board
CONN_LED_5V: J7.10, J7.14, J8.22; also elsewhere on the board
CONN_LED_12V: J7.11; also elsewhere on the board
CONN_LED_CHECK: J8.18; also elsewhere on the board
CONN_LED_COM: J7.9; also elsewhere on the board
CONN_LED_ERROR: J7.3; also elsewhere on the board
CONN_LED_INPUT: J7.12; also elsewhere on the board
CONN_LED_LOW_VOLTAGE: J7.2; also elsewhere on the board
CONN_LED_RS485_ACCESS: J7.4; also elsewhere on the board
CONN_LED_SAFTEY: J8.20; also elsewhere on the board
CONN_LED_TASK: J7.8; also elsewhere on the board
CONN_LED_USB_ACCESS: J7.7; also elsewhere on the board
CTL_KILL: J8.8; also elsewhere on the board
CTL_RESET: J7.13; also elsewhere on the board
CTL_RUN: J8.10; also elsewhere on the board
CTL_SAFETY: J8.19; also elsewhere on the board
GND: J7.1, J8.1; also elsewhere on the board
SW_CHECK: J8.21; also elsewhere on the board


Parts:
D8, D10: LED_B; LED_0603_1608Metric_Pad1.05x0.95mm_HandSolder
D9, D11, D12, D17, D18, D19, D20, D21, D22, D23, D24, D25, D26: LED_O; LED_0603_1608Metric_Pad1.05x0.95mm_HandSolder
D13, D15: LED_R; LED_0603_1608Metric_Pad1.05x0.95mm_HandSolder
D14, D16: LED_G; LED_0603_1608Metric_Pad1.05x0.95mm_HandSolder
R27, R29, R31, R32, R34, R36, R37, R38, R39, R40, R41, R42, R43, R44, R45: 1kR; R_0603_1608Metric_Pad0.98x0.95mm_HandSolder
R28: 3.6kR; R_0603_1608Metric_Pad0.98x0.95mm_HandSolder
R30: 2.4kR; R_0603_1608Metric_Pad0.98x0.95mm_HandSolder
R33, R35: 2.2kR; R_0603_1608Metric_Pad0.98x0.95mm_HandSolder

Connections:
CONN_LED_5V: D8.2 (A), R31.1; also elsewhere on the board
CONN_LED_12V: R30.1; also elsewhere on the board
CONN_LED_CHECK: R44.1; also elsewhere on the board
CONN_LED_COM: R33.1; also elsewhere on the board
CONN_LED_ERROR: R32.1; also elsewhere on the board
CONN_LED_INPUT: R28.1; also elsewhere on the board
CONN_LED_LOW_VOLTAGE: R34.1; also elsewhere on the board
CONN_LED_RS485_ACCESS: R29.1; also elsewhere on the board
CONN_LED_SAFTEY: R36.1; also elsewhere on the board
CONN_LED_TASK: R35.1; also elsewhere on the board
CONN_LED_USB_ACCESS: R27.2; also elsewhere on the board
CTL_CLOSE: R40.1; also elsewhere on the board
CTL_DUMP: R43.1; also elsewhere on the board
CTL_FILL: R41.1; also elsewhere on the board
CTL_IGNITOR: R37.1; also elsewhere on the board
CTL_O2: R45.1; also elsewhere on the board
CTL_OPEN: R38.1; also elsewhere on the board
CTL_PURGE: R42.1; also elsewhere on the board
CTL_SHIFT: R39.1; also elsewhere on the board
GND: D9.1 (K), D10.1 (K), D11.1 (K), D12.1 (K), D13.1 (K), D14.1 (K), D15.1 (K), D16.1 (K), D17.1 (K), D18.1 (K), D19.1 (K), D20.1 (K), D21.1 (K), D22.1 (K), D23.1 (K), D24.1 (K), D25.1 (K), D26.1 (K); also elsewhere on the board
unnamed: D8.1 (K), R27.1
unnamed: D9.2 (A), R28.2
unnamed: D10.2 (A), R29.2
unnamed: D11.2 (A), R30.2
unnamed: D12.2 (A), R31.2
unnamed: D13.2 (A), R32.2
unnamed: D14.2 (A), R33.2
unnamed: D15.2 (A), R34.2
unnamed: D16.2 (A), R35.2
unnamed: D17.2 (A), R36.2
unnamed: D18.2 (A), R37.2
unnamed: D19.2 (A), R38.2
unnamed: D20.2 (A), R39.2
unnamed: D21.2 (A), R40.2
unnamed: D22.2 (A), R41.2
unnamed: D23.2 (A), R42.2
unnamed: D24.2 (A), R43.2
unnamed: D25.2 (A), R44.2
unnamed: D26.2 (A), R45.2

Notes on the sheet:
LED_CLOSE
LED_ERROR
LED_RS485_ACCESS
LED_DUMP
LED_TASK
LED_PURGE
LED_FILL
LED_LOW_VOLTAGE
LED_O2
LED_COM
LED_5V
LED_SHIFT
LED_USB_ACCESS
LED_IGNITOR
LED_OPEN
LED_INPUT
LED_SAFETY
LED_12V
LED_CHECK

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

Board: 2 copper layers, 150.0 x 100.0 mm, 185 parts (0 on the bottom side), 133 nets.

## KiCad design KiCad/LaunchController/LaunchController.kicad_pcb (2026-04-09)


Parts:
C1, C2, C3, C5, C6, C7, C8, C11: 0.1uF; C_0603_1608Metric_Pad1.08x0.95mm_HandSolder
C9, C10: 15pF; C_0603_1608Metric_Pad1.08x0.95mm_HandSolder
D1: GS1010FL; D_SOD-123F
D2, D3: SMAJ45A; D_SMA_Handsoldering
D30: LED_O; LED_0603_1608Metric_Pad1.05x0.95mm_HandSolder
F1: MF-NSMF050; Fuse_1206_3216Metric_Pad1.42x1.75mm_HandSolder
J1: CONN_ICSP; PinSocket_1x06_P2.54mm_Vertical
J2: CONN_USB; TB401-1-4-E
J3: USB_B_Micro; USB_Micro-B_Wuerth_629105150521
L1: 10uH; L_1210_3225Metric_Pad1.42x2.65mm_HandSolder
R1, R6, R7: 10kR; R_0603_1608Metric_Pad0.98x0.95mm_HandSolder
R2, R3: 22R; R_0603_1608Metric_Pad0.98x0.95mm_HandSolder
R4, R8, R9, R10, R23, R27: 1kR; R_0603_1608Metric_Pad0.98x0.95mm_HandSolder
R5: 1MR; R_0603_1608Metric_Pad0.98x0.95mm_HandSolder
U1: FT232RL; SSOP-28_5.3x10.2mm_P0.65mm
U2: ATMEGA2560-16AUR; TQFP-100_14x14mm_P0.5mm
Y1: HUSG-16.000-20; Crystal_HC49-U_Vertical

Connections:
7SEG_CLK: U2.89 (PK0); also elsewhere on the board
7SEG_DIO: U2.88 (PK1); also elsewhere on the board
CONN_LED_5V: C1.1, C2.1, C3.1, C5.2, D1.1 (K), F1.2, J1.2, L1.2, R1.1, R6.1, R7.1, U1.4 (VCCIO), U1.20 (VCC), U2.10 (VCC), U2.31 (VCC), U2.61 (VCC), U2.80 (VCC); also elsewhere on the board
CONN_LED_CLOSE: U2.23 (PB4); also elsewhere on the board
CONN_LED_COM: U2.84 (PK5); also elsewhere on the board
CONN_LED_DUMP: U2.24 (PB5); also elsewhere on the board
CONN_LED_EMERGENCY: U2.29 (PG4); also elsewhere on the board
CONN_LED_ERROR: U2.83 (PK6); also elsewhere on the board
CONN_LED_FILL: U2.19 (PB0); also elsewhere on the board
CONN_LED_IGNITOR: U2.16 (PH4); also elsewhere on the board
CONN_LED_LOW_VOLTAGE: U2.82 (PK7); also elsewhere on the board
CONN_LED_O2: U2.39 (PL4); also elsewhere on the board
CONN_LED_OPEN: U2.18 (PH6); also elsewhere on the board
CONN_LED_PURGE: U2.25 (PB6); also elsewhere on the board
CONN_LED_RS485_ACCESS: U2.74 (PA4); also elsewhere on the board
CONN_LED_SAFTEY: U2.27 (PH7); also elsewhere on the board
CONN_LED_SEQUENCE: U2.28 (PG3); also elsewhere on the board
CONN_LED_SHIFT: U2.17 (PH5); also elsewhere on the board
CONN_LED_TASK: U2.85 (PK4); also elsewhere on the board
CONN_LED_USB_ACCESS: U1.22 (CBUS1), U1.23 (CBUS0); also elsewhere on the board
CTL_CLOSE: U2.51 (PG0); also elsewhere on the board
CTL_CONFIRM_1: U2.60 (PC7); also elsewhere on the board
CTL_CONFIRM_2: U2.59 (PC6); also elsewhere on the board
CTL_CONFIRM_3: U2.58 (PC5); also elsewhere on the board
CTL_DUMP: U2.52 (PG1); also elsewhere on the board
CTL_EMERGENCY_STOP: U2.57 (PC4); also elsewhere on the board
CTL_FILL: U2.48 (PD5); also elsewhere on the board
CTL_IGNITOR: U2.50 (PD7); also elsewhere on the board
CTL_KILL: U2.64 (PJ1); also elsewhere on the board
CTL_O2: U2.54 (PC1); also elsewhere on the board
CTL_OPEN: U2.49 (PD6); also elsewhere on the board
CTL_POWER: U2.92 (PF5); also elsewhere on the board
CTL_PURGE: U2.53 (PC0); also elsewhere on the board
CTL_RESET: C8.2, D1.2 (A), J1.5, R1.2, U2.30 (~RESET); also elsewhere on the board
CTL_RS485_DERE: U2.76 (PA2); also elsewhere on the board
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

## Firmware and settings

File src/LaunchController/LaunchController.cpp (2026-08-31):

#define MSGPACK_MAX_ARRAY_SIZE 12
#include "Input.hpp"
#include "Output.hpp"
#include "PowerMonitor.hpp"
#include "SemiAutoControl.hpp"
#include "TM1637.hpp"
#include "Thermistor.hpp"
#include <Arduino.h>
#include <DFPlayer_Mini_Mp3.h>
#include <MsgPacketizer.h>
#include <TaskManager.h>

namespace power
{
  Input killButton(PIN_PJ1, false);
  Output loadSwitch(PIN_PF5);
  Output powerLamp(PIN_PG5);
  Output lowVoltageLamp(PIN_PK7);

  PowerMonitor input(0x40);
  PowerMonitor bus12(0x41);
  Thermistor thermal(PIN_PF4, 10000.0);

  void measureTask();
} // namespace power

namespace control
{
  SemiAutoControl safetyArmed(PIN_PC2, false, PIN_PH7);
  SemiAutoControl sequenceStart(PIN_PC3, false, PIN_PG3);
  SemiAutoControl emergencyStop(PIN_PC4, true, PIN_PG4);

  Input confirm1(PIN_PC7, false);
  Input confirm2(PIN_PC6, false);
  Input confirm3(PIN_PC5, false);

  SemiAutoControl shift(PIN_PD4, false, PIN_PH5);
  SemiAutoControl fill(PIN_PD5, false, PIN_PB0);
  SemiAutoControl dump(PIN_PG1, false, PIN_PB5);
  SemiAutoControl oxygen(PIN_PC1, false, PIN_PL4);
  SemiAutoControl igniter(PIN_PD7, false, PIN_PH4);
  SemiAutoControl open(PIN_PD6, false, PIN_PH6);
  SemiAutoControl close(PIN_PG0, false, PIN_PB4);
  SemiAutoControl purge(PIN_PC0, false, PIN_PB6);

  Output shiftFB(PIN_PE3);
  Output fillFB(PIN_PE5);
  Output dumpFB(PIN_PE7);
  Output oxygenFB(PIN_PH3);
  Output igniterFB(PIN_PE2);
  Output openFB(PIN_PE4);
  Output closeFB(PIN_PE6);
  Output purgeFB(PIN_PH2);

  Output statusLamp(PIN_PK4); // Task
  void handleManualTask();

  const String FILL_START = "fill-start";
  const String FILL_STOP = "fill-stop";
  const String OXYGEN_START = "oxygen-start";
  const String OXYGEN_STOP = "oxygen-stop";
  const String IGNITER_START = "igniter-start";
  const String IGNITER_STOP = "igniter-stop";
  const String OPEN_START = "open-start";
  const String PLAY_MUSIC = "play-music";
  const String PURGE_START = "purge-start";
  const String PURGE_STOP = "purge-stop";

  void setChristmasTreeStart();
  void setChristmasTreeStop();
  void setEmergencyStop();
  void setPeacefulStop();
  void setFillStart();
  void setFillStop();
  void setOxygenStart();
  void setOxygenStop();
  void setIgniterStart();
  void setIgniterStop();
  void setOpenStart();
  void setPurgeStart();
  void setPurgeStop();
} // namespace control

namespace sequence
{
  void emergencyStop();
  void peacefulStop();
  void fill();
  void ignition();

  uint32_t sequenceStartRiseCount = 0;

  bool emergencyStopSequenceIsActive = false;
  bool fillSequenceIsActive = false;
  bool ignitionSequenceIsActive = false;
  bool canConfirm = false;
} // namespace sequence

namespace n2o
{
  TM1637 tm1637(PIN_PK0, PIN_PK1);

  // --- キャリブレーション設定 ---
  // 高圧ガス試験で求めた値をここに記入してください
  const float SENSOR_FS_MPa = 10.0f;  // 定格圧力
  const float CALIB_SLOPE_A = 0.5777; // 傾き (理論値は FS/16) //default -> SENSOR_FS_MPa / 16.0f
  // 2026/02/21 手動手押しポンプと精製水を用いて圧力を発生させた．
  const float CALIB_INTERCEPT_B = -CALIB_SLOPE_A * 4.0f; // 切片 (理論値は -a*4)
  // ----------------------------------------
} // namespace n2o

namespace error
{
  // HACK LEDだけでなく処理もする
  Output statusLamp(PIN_PK6); // ERR
} // namespace error

namespace communication
{
  enum class Packet : uint8_t
  {
    CONTROL_SYNC,              // 操作卓からの制御コマンド同期（電磁弁開閉など）
    FEEDBACK_SYNC,             // 機体からのフィードバック（電磁弁の実際の状態など）
    PRESSURE_SYNC,             // 算出された圧力値(MPa)の同期
    COM_CHECK_L_TO_S,          // 操作卓から機体への生存確認（通信チェック）
    COM_CHECK_S_TO_L,          // 機体から操作卓への生存確認（通信チェック）
    SENSOR_CONFIG_SYNC,        // センサの基本設定（フルスケールなど）の同期
    SENSOR_DUMMY_CURRENT_SYNC, // シミュレーション用のダミー電流値同期
    SENSOR_CALIB_COEFF_SYNC,   // 校正係数(a, b)同期用
    SENSOR_ZERO_CALIB_REQ,     // ゼロ点校正実行要求用
    SENSOR_CURRENT_SYNC,       // 生の電流値(mA)同期用
    LIMIT_SWITCH_SYNC = 10,
    COM_CHECK_L_TO_N = 11,
    COM_CHECK_N_TO_L = 12,
    SATELLITE_VOLTAGE_SYNC = 13,
    SATELLITE_BUS_VOLTAGE_SYNC = 14,
    SATELLITE_ARMED_SYNC = 15,

    // --- Raspberry Pi 4 無線通信用パケット ---
    RASPI_COMMAND = 0x20,            // (32) Raspberry Pi 4 からの遠隔制御コマンド
    RASPI_HEARTBEAT_L_TO_R = 0x21,   // (33) Launch3.0 → Raspberry Pi 4 生存確認
    RASPI_HEARTBEAT_R_TO_L = 0x22,   // (34) Raspberry Pi 4 → Launch3.0 生存確認
    RASPI_TELEMETRY = 0x23,          // (35) テレメトリ一括送信
    RASPI_WIRELESS_STATUS = 0x24,    // (36) 無線リンク状態報告
  };

  Output sendEnableControl(PIN_PA2);
  Output accessLamp(PIN_PA4); // RS485

  // bool checkFailed = false;

  unsigned long preReceivedTime = 0;
  const long timeout = 5000;

  void enableOutput();
  void disableOutput();

  void sendControlSync();
  void sendComCheck();
  void onFeedbackSyncReceived(uint8_t state);
  void onSatelliteVoltageSyncReceived(float voltage);
  void onSatelliteBusVoltageSyncReceived(float voltage);
  void onSatelliteArmedSyncReceived(uint8_t isArmed);
  void onPressureSyncReceived(float pressure);
  void onCurrentSyncReceived(float current_mA); // 電流受信ハンドラ
  void onComCheckReceived();
  void onComCheckFailed();
  void sendSensorConfigSync();
  void sendSensorDummyCurrent(float current_mA);
  void sendSensorCalibCoeff(float a, float b);
  void sendSensorZeroCalibReq();
  void sendTelemetryForPython();

  Output statusLamp(PIN_PK5); // COM
} // namespace communication

namespace simulation
{

  void updateTask() { communication::sendSensorDummyCurrent(0.0f); }

} // namespace simulation

namespace raspi_wireless
{
  unsigned long lastHeartbeatTime = 0;
  const unsigned long WIRELESS_TIMEOUT_MS = 3000;
  bool isWirelessConnected = false;
  bool remoteArmingState = false;
  float latestPressure_MPa = 0.0f;
  float latestSatelliteVoltage_V = 0.0f;
  float latestSatelliteBusVoltage_V = 0.0f;
  bool latestSatelliteArmed = false;

  enum class RemoteCmd : uint8_t
  {
    EMERGENCY_STOP = 1,
    PEACEFUL_STOP  = 2,
    FILL_START     = 3,
    IGNITION_START = 4,
    ARM_SAFETY     = 5,
    VALVE_CONTROL  = 6,
    ZERO_CALIB     = 7,
  };

  void checkWirelessTask();
  void sendWirelessTelemetryTask();
  void onRaspiHeartbeatReceived();
  void onRaspiCommandReceived(uint8_t cmdType, uint8_t param);
} // namespace raspi_wireless

void setup()
{
  pinMode(PIN_PB7, OUTPUT);
  digitalWrite(PIN_PB7, HIGH);
  power::loadSwitch.on();
  power::powerLamp.on();

  // FT232RL (USB)
  Serial.begin(115200);

  // LTC485 (RS485)
  Serial1.begin(115200);
  communication::disableOutput();
  communication::preReceivedTime = millis() - communication::timeout;

  // DFPlayer (Audio)
  Serial2.begin(9600);
  mp3_set_serial(Serial2);
  mp3_stop();
  mp3_set_volume(30);

  // TM1637 (7SEG)
  n2o::tm1637.initialize();

  // INA219 (Power)
  Wire.begin();
  power::input.begin();
  power::bus12.begin();

  raspi_wireless::lastHeartbeatTime = millis();

  Tasks.add(&power::measureTask)->startFps(10);
  Tasks.add(&control::handleManualTask)->startFps(10);
  Tasks.add(&communication::sendControlSync)->startFps(10);
  // Tasks.add(&communication::sendComCheck)->startFps(2); // コリジョン防止のため無効化
  Tasks.add(&communication::onComCheckFailed)->startFps(2);
  // Tasks.add(&communication::sendTelemetryForPython)
  //     ->startFps(10); // 10HzでPCへ状態送信
  // Tasks.add(&simulation::updateTask)->startFps(2);

  Tasks.add(&raspi_wireless::checkWirelessTask)->startFps(2);
  Tasks.add(&raspi_wireless::sendWirelessTelemetryTask)->startFps(10);
  communication::sendSensorConfigSync();
  // 起動時に実測校正係数を同期
  communication::sendSensorCalibCoeff(n2o::CALIB_SLOPE_A,
                                      n2o::CALIB_INTERCEPT_B);

  MsgPacketizer::subscribe(
      Serial1, static_cast<uint8_t>(communication::Packet::FEEDBACK_SYNC),
      &communication::onFeedbackSyncReceived);
  MsgPacketizer::subscribe(
      Serial1, static_cast<uint8_t>(communication::Packet::PRESSURE_SYNC),
      &communication::onPressureSyncReceived);
  MsgPacketizer::subscribe(
      Serial1, static_cast<uint8_t>(communication::Packet::SENSOR_CURRENT_SYNC),
      &communication::onCurrentSyncReceived);
  MsgPacketizer::subscribe(
      Serial1, static_cast<uint8_t>(communication::Packet::SATELLITE_VOLTAGE_SYNC),
      &communication::onSatelliteVoltageSyncReceived);
  MsgPacketizer::subscribe(
      Serial1, static_cast<uint8_t>(communication::Packet::SATELLITE_BUS_VOLTAGE_SYNC),
      &communication::onSatelliteBusVoltageSyncReceived);
  MsgPacketizer::subscribe(
      Serial1, static_cast<uint8_t>(communication::Packet::SATELLITE_ARMED_SYNC),
      &communication::onSatelliteArmedSyncReceived);
  MsgPacketizer::subscribe(
      Serial1, static_cast<uint8_t>(communication::Packet::COM_CHECK_S_TO_L),
      &communication::onComCheckReceived);

  MsgPacketizer::subscribe(
      Serial, static_cast<uint8_t>(communication::Packet::RASPI_HEARTBEAT_R_TO_L),
      &raspi_wireless::onRaspiHeartbeatReceived);
  MsgPacketizer::subscribe(
      Serial, static_cast<uint8_t>(communication::Packet::RASPI_COMMAND),
      &raspi_wireless::onRaspiCommandReceived);

  // シーケンス関係のタスクたち
  Tasks.add(control::FILL_START, &control::setFillStart);
  Tasks.add(control::FILL_STOP, &control::setFillStop);
  Tasks.add(control::OXYGEN_START, &control::setOxygenStart);
  Tasks.add(control::OXYGEN_STOP, &control::setOxygenStop);
  Tasks.add(control::IGNITER_START, &control::setIgniterStart);
  Tasks.add(control::IGNITER_STOP, &control::setIgniterStop);
  Tasks.add(control::OPEN_START, &control::setOpenStart);
  Tasks.add(control::PURGE_START, &control::setPurgeStart);
  Tasks.add(control::PURGE_STOP, &control::setPurgeStop);
  Tasks.add(control::PLAY_MUSIC, []
            { mp3_play(9); });

  control::setChristmasTreeStart();
  Tasks.add(&control::setChristmasTreeStop)->startOnceAfterSec(3.0);

  // 起動5秒後に、その場の環境に合わせて自動でゼロ点校正を実行
  Tasks
      .add([]
           {
        Serial.println(">>> Requesting Remote Zero-Point Calibration...");
        communication::sendSensorZeroCalibReq(); })
      ->startOnceAfterSec(5.02); // 50ms周期のCONTROL_SYNCとの衝突を避けるため5.02秒にずらす

  mp3_play(11);
}

void loop()
{
  MsgPacketizer::parse();
  Tasks.update();

  communication::accessLamp.update();
  control::statusLamp.update();
}

/// @brief 送信を有効にする
void communication::enableOutput()
{
  communication::sendEnableControl.on();
  delayMicroseconds(50);
  communication::accessLamp.pulse(10);
}

/// @brief 送信を無効にする
void communication::disableOutput()
{
  delayMicroseconds(500);
  communication::sendEnableControl.off();
}

void power::measureTask()
{
  bool isLowVoltage = power::input.getVoltage_V() < 11.5;
  bool isOverloadedInput = power::input.getAmpere_A() > 3.0;
  bool isOverloadedBus = power::bus12.getAmpere_A() > 3.0;
  bool isOverheated = power::thermal.getTemperature_degC() > 100.0;

  power::lowVoltageLamp.set(isLowVoltage);

  bool isSequenceStartMistake = control::sequenceStart.isManualRaised() &&
                                !control::dump.isManualRaised() &&
                                !sequence::emergencyStopSequenceIsActive;

  // Teleplot 用
  // Serial.print(">Tempelature_degC:"); // 12V-5V レギュレーターの温度モニター
  // Serial.println(power::thermal.getTemperature_degC());
  // Serial.print(">inputVoltage_V:"); // 入力電圧モニター
  // Serial.println(power::input.getVoltage_V());
  // Serial.print(">inputAmpere_A:"); // 入力電流モニター
  // Serial.println(power::input.getAmpere_A());
  // Serial.print(">bus12Voltage_V:"); // 12Vバス電圧モニター
  // Serial.println(power::bus12.getVoltage_V());

  if (isOverloadedInput || isOverloadedBus || isOverheated)
  {
    // HACK エラー
    error::statusLamp.on();
  }

  if (isSequenceStartMistake)
  {
    error::statusLamp.on();
  }
  else if (control::dump.isManualRaised() ||
           sequence::emergencyStopSequenceIsActive)
  {
    error::statusLamp.off();
  }
}

void communication::sendControlSync()
{
  uint8_t state =
      (control::shift.isRaised() << 0) | (control::fill.isRaised() << 1) |
      (control::dump.isRaised() << 2) | (control::oxygen.isRaised() << 3) |
      (control::igniter.isRaised() << 4) | (control::open.isRaised() << 5) |
      (control::close.isRaised() << 6) | (control::purge.isRaised() << 7);

  communication::enableOutput();
  Serial.print("[LAUNCH] TX CONTROL_SYNC -> Satellite (state=0x");
  Serial.print(state, HEX);
  Serial.println(")");
  MsgPacketizer::send(Serial1,
                      static_cast<uint8_t>(communication::Packet::CONTROL_SYNC),
                      state);
  Serial1.flush();
  communication::disableOutput();
}

void communication::sendSensorConfigSync()
{
  communication::enableOutput();
  MsgPacketizer::send(
      Serial1, static_cast<uint8_t>(communication::Packet::SENSOR_CONFIG_SYNC),
      10.0f); // Default 10.0 MPa
  Serial1.flush();
  communication::disableOutput();
}

void communication::sendSensorDummyCurrent(float current_mA)
{
  communication::enableOutput();
  MsgPacketizer::send(
      Serial1,
      static_cast<uint8_t>(communication::Packet::SENSOR_DUMMY_CURRENT_SYNC),
      current_mA);
  Serial1.flush();
  communication::disableOutput();
}

/**
 * @brief センサ校正係数の送信（同期）
 * @param a 傾き (Pressure = a * Current + b)
 * @param b 切片
 */
void communication::sendSensorCalibCoeff(float a, float b)
{
  communication::enableOutput();
  MsgPacketizer::send(
      Serial1,
      static_cast<uint8_t>(communication::Packet::SENSOR_CALIB_COEFF_SYNC), a,
      b);
  Serial1.flush();
  communication::disableOutput();
}

/**
 * @brief ゼロ点校正（大気圧校正）の実行リクエストを送信
 */
void communication::sendSensorZeroCalibReq()
{
  communication::enableOutput();
  MsgPacketizer::send(
      Serial1,
      static_cast<uint8_t>(communication::Packet::SENSOR_ZERO_CALIB_REQ));
  Serial1.flush();
  communication::disableOutput();
}

void communication::sendComCheck()
{
  communication::enableOutput();
  MsgPacketizer::send(
      Serial1, static_cast<uint8_t>(communication::Packet::COM_CHECK_L_TO_S));
  Serial1.flush();
  communication::disableOutput();
}

void communication::onFeedbackSyncReceived(uint8_t state)
{
  Serial.print("[LAUNCH] RX SUCCESS! FEEDBACK_SYNC state = 0x");
  Serial.println(state, HEX);

  control::shiftFB.set(state & (1 << 0));
  control::fillFB.set(state & (1 << 1));
  control::dumpFB.set(state & (1 << 2));
  control::oxygenFB.set(state & (1 << 3));
  control::igniterFB.set(state & (1 << 4));
  control::openFB.set(state & (1 << 5));
  control::closeFB.set(state & (1 << 6));
  control::purgeFB.set(state & (1 << 7));
}

void communication::onSatelliteVoltageSyncReceived(float voltage)
{
  raspi_wireless::latestSatelliteVoltage_V = voltage;
}

void communication::onSatelliteBusVoltageSyncReceived(float voltage)
{
  raspi_wireless::latestSatelliteBusVoltage_V = voltage;
}

void communication::onSatelliteArmedSyncReceived(uint8_t isArmed)
{
  raspi_wireless::latestSatelliteArmed = (isArmed != 0);
}

void communication::onPressureSyncReceived(float pressure)
{
  n2o::tm1637.displayNumber(pressure);
  raspi_wireless::latestPressure_MPa = pressure;

  // communication::statusLamp.blink();
}

/**
 * @brief 機体から受信した生の電流値(mA)をシリアル出力
 */
void communication::onCurrentSyncReceived(float current_mA)
{
  Serial.print(">VESIM10 Current: ");
  Serial.println(current_mA);
}

void communication::onComCheckReceived()
{
  communication::statusLamp.on();
  error::statusLamp.off();
  communication::preReceivedTime = millis();
}

void communication::onComCheckFailed()
{
  if (millis() - communication::preReceivedTime > communication::timeout)
  {
    communication::statusLamp.off();
    error::statusLamp.on();

    // ★重要：シーケンス実行中に通信が切れたら、強制的にシーケンスを止める
    if (sequence::fillSequenceIsActive || sequence::ignitionSequenceIsActive)
    {
      sequence::peacefulStop();
    }

    control::fillFB.off();
    control::dumpFB.off();
    control::oxygenFB.off();
    control::igniterFB.off();
    control::openFB.off();
    control::closeFB.off();
    control::purgeFB.off();

    // ★機体通信切断時はセンサ・電圧データを0または無効値にリセットする
    raspi_wireless::latestSatelliteVoltage_V = 0.0f;
    raspi_wireless::latestSatelliteBusVoltage_V = 0.0f;
    raspi_wireless::latestSatelliteArmed = false;
    raspi_wireless::latestPressure_MPa = 0.0f;
    n2o::tm1637.clearDisplay();
  }
}

/**
 * @brief Python GUI (Visualizer) 用に現在の状態をSerial出力
 * フォーマット: V_DATA:<CMD_BITS>,<FB_BITS>
 */
void communication::sendTelemetryForPython()
{
  uint8_t cmd_state =
      (control::shift.isRaised() << 0) | (control::fill.isRaised() << 1) |
      (control::dump.isRaised() << 2) | (control::oxygen.isRaised() << 3) |
      (control::igniter.isRaised() << 4) | (control::open.isRaised() << 5) |
      (control::close.isRaised() << 6) | (control::purge.isRaised() << 7);

  uint8_t fb_state =
      (control::shiftFB.isHigh() << 0) | (control::fillFB.isHigh() << 1) |
      (control::dumpFB.isHigh() << 2) | (control::oxygenFB.isHigh() << 3) |
      (control::igniterFB.isHigh() << 4) | (control::openFB.isHigh() << 5) |
      (control::closeFB.isHigh() << 6) | (control::purgeFB.isHigh() << 7);

  Serial.print("V_DATA:");
  Serial.print(cmd_state);
  Serial.print(",");
  Serial.println(fb_state);
}

void control::handleManualTask()
{
  control::statusLamp.pulse(50);

  if (power::killButton.isHigh())
  {
    mp3_play(12);
    power::powerLamp.off();
    delay(500);
    power::powerLamp.on();
    delay(500);
    power::powerLamp.off();
    delay(500);
    power::powerLamp.on();
    delay(500);
    power::powerLamp.off();
    delay(500);
    power::powerLamp.on();
    delay(500);
    power::powerLamp.off();
    delay(500);
    power::loadSwitch.off();
  }

  // セーフティー
  // Armedでなければこの時点で終わり
  control::safetyArmed.setManual();
  if (!control::safetyArmed.isManualRaised() && !raspi_wireless::remoteArmingState)
  {
    // シーケンスが進行中なら穏便ストップ
    if (sequence::emergencyStopSequenceIsActive ||
        sequence::fillSequenceIsActive || sequence::ignitionSequenceIsActive)
    {
      sequence::peacefulStop();
    }

    return;
  }

  // エマスト
  control::emergencyStop.setManual();
  if (control::emergencyStop.isManualRaised())
  {
    sequence::emergencyStop();
  }

  // 充填シーケンス
  control::sequenceStart.setManual();

  // DUMPがCLOSEされていない場合，シークエンス開始ボタンを押してもシークエンスが開始されない
  if (control::sequenceStart.isManualRaised() &&
      !control::dump.isManualRaised() &&
      !sequence::emergencyStopSequenceIsActive)
  {
    mp3_play(13);
    return;
  }

  if (control::sequenceStart.isManualRaised())
  {
    if (sequence::sequenceStartRiseCount == 0)
    {
      if (!(sequence::emergencyStopSequenceIsActive ||
            sequence::fillSequenceIsActive ||
            sequence::ignitionSequenceIsActive))
      {
        sequence::fill();
      }
      // 充填確認スイッチの代替
      else if (sequence::canConfirm)
      {
        sequence::ignition();
      }
      else
      {
        sequence::peacefulStop();
      }
    }

    sequence::sequenceStartRiseCount++;
  }
  else
  {
    sequence::sequenceStartRiseCount = 0;
  }

  // 点火シーケンス
  if (control::confirm1.isHigh() && control::confirm2.isHigh() &&
      control::confirm3.isHigh()) // 3人同時押しで充填確認するように変更
  {
    sequence::ignition();
  }

  // 手動制御
  control::shift.setManual();
  control::fill.setManual();
  control::dump.setManual();
  control::oxygen.setManual();
  control::igniter.setManual();
  control::open.setManual();
  control::close.setManual();
  control::purge.setManual();
}

void sequence::emergencyStop()
{
  // 重複実行防止
  if (sequence::emergencyStopSequenceIsActive)
    return;

  sequence::emergencyStopSequenceIsActive = true;

  sequence::fillSequenceIsActive = false;
  sequence::ignitionSequenceIsActive = false;
  sequence::canConfirm = false;

  control::emergencyStop.setAutomaticOn();
  mp3_play(3); // 0102_emergencyStop.mp3

  control::sequenceStart.setAutomaticOff();

  Tasks[control::PLAY_MUSIC]->stop();
  Tasks[control::FILL_START]->stop();
  Tasks[control::OXYGEN_START]->stop();
  Tasks[control::IGNITER_START]->stop();
  Tasks[control::FILL_STOP]->stop();
  Tasks[control::OPEN_START]->stop();
  Tasks[control::OXYGEN_STOP]->stop();
  Tasks[control::IGNITER_STOP]->stop();

  control::setEmergencyStop();
}

void sequence::peacefulStop()
{
  control::sequenceStart.setAutomaticOff();

  sequence::emergencyStopSequenceIsActive = false;
  sequence::fillSequenceIsActive = false;
  sequence::ignitionSequenceIsActive = false;
  sequence::canConfirm = false;

  control::sequenceStart.setAutomaticOff();
  control::emergencyStop.setAutomaticOff();

  Tasks[control::PLAY_MUSIC]->stop();
  Tasks[control::FILL_START]->stop();
  Tasks[control::OXYGEN_START]->stop();
  Tasks[control::IGNITER_START]->stop();
  Tasks[control::PURGE_START]->stop();
  Tasks[control::FILL_STOP]->stop();
  Tasks[control::OPEN_START]->stop();
  Tasks[control::OXYGEN_STOP]->stop();
  Tasks[control::IGNITER_STOP]->stop();
  Tasks[control::PURGE_STOP]->stop();

  mp3_stop();
  control::setPeacefulStop();
}

void sequence::fill()
{
  // 重複実行防止
  if (sequence::fillSequenceIsActive)
    return;

  // エマスト中は充填シーケンスを始めない
  if (sequence::emergencyStopSequenceIsActive)
    return;

  // シーケンス開始時点で充填確認されていたらエラーを吐く
  if (control::confirm1.isHigh() || control::confirm2.isHigh() ||
      control::confirm3.isHigh())
  {
    // HACK エラー
    sequence::peacefulStop();
    error::statusLamp.on();
    return;
  }

  // 通信失敗したらシーケンスに進めない
  if (!communication::statusLamp.isHigh())
  {
    sequence::peacefulStop();
    return;
  }

  sequence::fillSequenceIsActive = true;
  sequence::canConfirm = false;

  control::sequenceStart.setAutomaticOn();
  mp3_play(10);

  Tasks[control::PLAY_MUSIC]->startOnceAfterSec(15.0);
  Tasks[control::FILL_START]->startOnceAfterSec(24.0);
}
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

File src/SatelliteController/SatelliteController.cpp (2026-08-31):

#include "Input.hpp"
#include "Output.hpp"
#include "PowerMonitor.hpp"
#include "SemiAutoControl.hpp"
#include "SolenoidMonitor.hpp"
#include "TM1637.hpp"
#include "Thermistor.hpp"
#include "VESIM10.hpp"
#include <Arduino.h>
#include <MsgPacketizer.h>
#include <TaskManager.h>

namespace power
{
  Input killButton(PIN_PJ1, false);
  Output loadSwitch(PIN_PF5);
  Output powerLamp(PIN_PG5);
  Output lowVoltageLamp(PIN_PK7);

  PowerMonitor input(0x40);
  PowerMonitor bus12(0x41);
  Thermistor thermal(PIN_PF4, 10000.0);

  void measureTask();
} // namespace power

namespace control
{
  SemiAutoControl safetyArmed(PIN_PC2, true, PIN_PH7);

  Output shift(PIN_PD4);
  Output fill(PIN_PD5);
  Output dump(PIN_PG1);
  Output oxygen(PIN_PC3);
  Output igniter(PIN_PD7);
  Output open(PIN_PD6);
  Output close(PIN_PG0);
  // SemiAutoControl purge(PIN_PC0, false, PIN_PG3);
  SemiAutoControl purgeSwitch(PIN_PG4, true, PIN_PG3);
  Output purge(PIN_PC0);

  // Output purge(PIN_PB6);
  // SemiAutoControl check(PIN_PC0, true, PIN_PB6);

  Output shiftFB(PIN_PH5);
  Output fillFB(PIN_PB0);
  Output dumpFB(PIN_PB5);
  Output oxygenFB(PIN_PL4);
  Output igniterFB(PIN_PH4);
  Output openFB(PIN_PH6);
  Output closeFB(PIN_PB4);
  Output purgeFB(PIN_PH1);
  Output statusLamp(PIN_PK4);

  void handleManualTask();
  void setChristmasTreeStart();
  void setChristmasTreeStop();
} // namespace control

namespace error
{
  // HACK LEDだけでなく処理もする
  Output statusLamp(PIN_PK6);
} // namespace error

namespace solenoid
{
  SolenoidMonitor monitor(PIN_PC4);
  constexpr uint8_t FAULT_CONFIRM_COUNT = 5;

  struct Debouncer
  {
    SolenoidMonitor::Status lastRawStatus = SolenoidMonitor::Status::OFF;
    SolenoidMonitor::Status confirmedStatus = SolenoidMonitor::Status::OFF;
    uint8_t count = 0;

    SolenoidMonitor::Status update(SolenoidMonitor::Status newStatus)
    {
      if (newStatus == lastRawStatus)
      {
        count++;
      }
      else
      {
        lastRawStatus = newStatus;
        count = 1;
      }

      if (count >= FAULT_CONFIRM_COUNT)
      {
        confirmedStatus = newStatus;
      }
      return confirmedStatus;
    }

    void reset()
    {
      lastRawStatus = SolenoidMonitor::Status::OFF;
      confirmedStatus = SolenoidMonitor::Status::OFF;
      count = 0;
    }
  };

  Debouncer fillDebouncer;
  Debouncer dumpDebouncer;
  Debouncer oxygenDebouncer;
  Debouncer purgeDebouncer;

  void checkSolenoid(SolenoidMonitor::Solenoid solenoid, const char *name);
  void measureTask();
} // namespace solenoid

namespace n2o
{
  TM1637 tm1637(PIN_PK0, PIN_PK1);
  VESIM10 vesim10(PIN_PK2, 240.0, 10.0);

  // --- ゼロ点校正の安全設定 ---
  // 大気圧下において許容される生電流の範囲 (mA)
  // この範囲外の場合は、圧力が残っているかセンサ異常として校正をブロックします。
  const float CALIB_SAFE_CURRENT_MIN = 3.8;
  const float CALIB_SAFE_CURRENT_MAX = 4.2;
  // ---------------------------

  float pressure_MPa = 0.0;

  void measureTask();
  void samplingTask();
} // namespace n2o

namespace umbilical
{
  Output flightMode(PIN_PH3);
  Output valveMode(PIN_PH2);
} // namespace umbilical

namespace communication
{
  enum class Packet : uint8_t
  {
    CONTROL_SYNC = 0,
    FEEDBACK_SYNC = 1,
    PRESSURE_SYNC = 2,
    COM_CHECK_L_TO_S = 3,
    COM_CHECK_S_TO_L = 4,
    SENSOR_CONFIG_SYNC = 5,
    SENSOR_DUMMY_CURRENT_SYNC = 6,
    SENSOR_CALIB_COEFF_SYNC = 7,
    SENSOR_ZERO_CALIB_REQ = 8,
    SENSOR_CURRENT_SYNC = 9,
    LIMIT_SWITCH_SYNC = 10,
    COM_CHECK_L_TO_N = 11,
    COM_CHECK_N_TO_L = 12,
    SATELLITE_VOLTAGE_SYNC = 13,
    SATELLITE_BUS_VOLTAGE_SYNC = 14,
    SATELLITE_ARMED_SYNC = 15,

    RASPI_SATELLITE_TELEMETRY = 0x33, // (51) Raspberry Pi 4 へ機体詳細テレメトリ送信
    RASPI_WIRELESS_STATUS = 0x34,     // (52) 機体無線ステータス
  };

  Output sendEnableControl(PIN_PA2);
  Output accessLamp(PIN_PA4); // RS485

  uint8_t syncState;
  unsigned long preReceivedTime = 0;
  const long timeout = 5000;

  void enableOutput();
  void disableOutput();

  void sendReplyToLaunch();

  void onControlSyncReceived(uint8_t state);
  void onComCheckReceived();
  void onComCheckFailed();
  void onSensorConfigReceived(float fullScale_MPa);
  void onSensorDummyCurrentReceived(float dummyCurrent_mA);
  void onSensorCalibCoeffReceived(float a, float b);
  void onSensorZeroCalibReqReceived();

  Output statusLamp(PIN_PK5); // COM
} // namespace communication
namespace raspi_wireless
{
  unsigned long lastHeartbeatTime = 0;
  const unsigned long WIRELESS_TIMEOUT_MS = 3000;
  bool isWirelessConnected = false;

  void checkWirelessTask();
  void sendWirelessTelemetryTask();
  void onHeartbeatReceived();
} // namespace raspi_wireless

/// @brief 送信を有効にする
void communication::enableOutput()
{
  communication::sendEnableControl.on();
  delayMicroseconds(50);
  communication::accessLamp.pulse(50);
}

/// @brief 送信を無効にする
void communication::disableOutput()
{
  delayMicroseconds(500);
  communication::sendEnableControl.off();
}

void power::measureTask()
{
  bool isLowVoltage =
      power::input.getVoltage_V() < 10.5; // 電磁弁の許容電流に設定
  bool isOverloadedInput = power::input.getAmpere_A() > 3.0;
  bool isOverloadedBus = power::bus12.getAmpere_A() > 3.0;
  bool isOverheated = power::thermal.getTemperature_degC() > 100.0;

  power::lowVoltageLamp.set(isLowVoltage);

  if (isOverloadedInput || isOverloadedBus || isOverheated)
  {
    // HACK エラー
    error::statusLamp.on();
  }
}
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

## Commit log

2023-09-07 ランコンのKiCadプロジェクトを作成
    [LaunchController.kicad_pcb, LaunchController.kicad_sch]
2023-09-07 ランコンの回路図を作成
    [Interface.kicad_sch, LaunchController.kicad_pcb, LaunchController.kicad_sch]
2023-09-09 スイッチの接点方式を修正
    [Interface.kicad_sch, LaunchController.kicad_sch]
2023-09-09 LED用の抵抗値を設定
    [Interface.kicad_sch]
2023-09-09 一通り部品を選定
    [Interface.kicad_sch, LaunchController.kicad_pcb, LaunchController.kicad_sch]
2023-09-10 ボード設計中（地獄）
    [LaunchController.kicad_pcb, LaunchController.kicad_sch]
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2023-09-12 型を修正
2023-09-13 修正を回路図に反映
    [Interface.kicad_sch, LaunchController.kicad_sch]
2023-09-13 フィードバックLEDを追加
    [Interface.kicad_sch, LaunchController.kicad_sch]
2023-09-13 シートを分割
    [Indicator.kicad_sch, Interface.kicad_sch, LED.kicad_sch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]
2023-09-13 電圧から抵抗値を修正
    [Indicator.kicad_sch, LaunchController.kicad_pcb, LaunchController.kicad_sch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]
2023-09-13 ランスイッチにチャタリング対策を追加
    [Switch.kicad_sch]
2023-09-13 さらに分割
    [Extension.kicad_sch, Indicator.kicad_sch, LaunchController.kicad_sch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]
2023-09-14 基板寸法を設定
    [LaunchController.kicad_pcb]
2023-09-14 端子台を選定
    [Extension.kicad_sch, LaunchController.kicad_pcb, LaunchController.kicad_sch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]
2023-09-14 拡張スロットを削除
    [Extension.kicad_sch, LaunchController.kicad_pcb]
2023-09-14 配線終わらん
    [Extension.kicad_sch, LaunchController.kicad_pcb, LaunchController.kicad_sch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]
2023-09-15 シュミットトリガー無しで部品を配置
    [Extension.kicad_sch, LaunchController.kicad_pcb, LaunchController.kicad_sch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]
2023-09-18 リセット
    [Extension.kicad_sch, Indicator.kicad_sch, LaunchController.kicad_pcb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]
2023-09-18 基板外形を設定
    [LaunchController.kicad_pcb]
2023-09-18 電源周りできた
    [Extension.kicad_sch, Indicator.kicad_sch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]
2023-09-19 コネクタ少し追加
    [LaunchController.kicad_pcb]
2023-09-20 あとはDRC解決とビア打ち
    [Indicator.kicad_sch, LaunchController.kicad_pcb, LaunchController.kicad_sch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]
2023-09-20 刻印を追加
    [LaunchController.kicad_pcb]
2023-09-21 DRCエラーを解決
    [LaunchController.kicad_pcb]
2023-09-21 GNDビアを追加
    [LaunchController.kicad_pcb]
2023-09-21 ガーバーを出力
    [LaunchController-CuBottom.gbr, LaunchController-CuTop.gbr, LaunchController-EdgeCuts.gbr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]
2023-09-21 ランコンをコピーしてサテコンの回路図を作成
    [Extension.kicad_sch, Indicator.kicad_sch, LED.kicad_sch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]
2023-09-21 圧力センサとの接続部を追加
    [Extension.kicad_sch, Indicator.kicad_sch, Peripheral.kicad_sch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]
2023-09-21 スピーカーの配線を太めに変更
    [LaunchController.kicad_pcb]
2023-09-21 ジャンパーを回路図に追加
    [Extension.kicad_sch, Indicator.kicad_sch, LaunchController.kicad_pcb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]
2023-09-21 ランコンおわり
    [Extension.kicad_sch, Indicator.kicad_sch, LaunchController.kicad_pcb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]
2023-09-22 情報を追加
    [LaunchController.kicad_pcb]
2023-09-22 選定部品を調整
    [Indicator.kicad_sch, LaunchController.kicad_pcb, LaunchController.kicad_sch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]
2023-09-22 ロードスイッチの抵抗値を調整
    [LaunchController.kicad_pcb, LaunchController.kicad_sch, PartsList.xlsx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]
2023-09-22 購入部品リストを記載
    [PartsList.xlsx]
2023-09-22 ランコン基板をビルド
    [LaunchController.kicad_pcb]
2023-09-22 ヒロセコネクタを部品表に記載（購入先は未定）
    [PartsList.xlsx]
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2023-10-03 クラスの一部フィールドのアクセスレベルを修正
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2023-10-03 DFPlayerの音量の最大値は30らしいので修正
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2023-10-06 indentを修正
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2023-10-06 setup()内の実行順番を修正
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2023-10-10 充填シーケンス終了後、手動のFILLがONの間は点火シーケンスを始めないように修正
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2023-10-10 エマスト中はシーケンスを始めないように修正
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2023-10-10 セーフティーの処理を修正
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2023-10-11 エマスト時に全ての自動シーケンス関係のタスクを停止するように修正
2023-10-11 エマストで自動シーケンスを切るように修正
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2023-10-11 Outputの状態更新を修正
2023-10-11 シーケンス重複実行防止の優先順位を修正
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2023-10-13 プッシュインコネクタを修正
    [LaunchController.kicad_pcb]
2023-10-13 EDLCを削除
    [LaunchController.kicad_pcb, LaunchController.kicad_sch]
2023-10-13 RUNスイッチをGND接続に変更
    [LaunchController.kicad_pcb, Switch.kicad_sch]
2023-10-13 イラン抵抗を削除
    [LaunchController.kicad_pcb]
2023-10-13 TVSダイオードの極性が逆だったので修正
    [LaunchController.kicad_pcb, LaunchController.kicad_sch]
2023-10-13 ロードスイッチ駆動用のトランジスタのベース抵抗を10kRに修正
    [LaunchController.kicad_pcb, Power.kicad_sch]
2023-10-13 DFPlayerのTXにも抵抗を追加
    [LaunchController.kicad_pcb, LaunchController.kicad_sch]
2023-10-13 敗北ダイオードを追加
    [LaunchController.kicad_pcb, Peripheral.kicad_sch]
2023-10-13 サーミスタを分圧の下流側に変更
    [LaunchController.kicad_pcb, Power.kicad_sch]
2023-10-13 イラン分圧回路を削除
    [Indicator.kicad_sch, LaunchController.kicad_pcb, Power.kicad_sch]
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2023-10-13 RJ45をヒロセに変更
    [LaunchController.kicad_pcb, Peripheral.kicad_sch]
2023-10-13 7セグ制御端子を追加
    [LaunchController.kicad_pcb, LaunchController.kicad_sch]
2023-10-13 未接続の配線を修正
    [LaunchController.kicad_pcb]
2023-10-13 ティアドロップを追加
    [LaunchController.kicad_pcb]
2023-10-13 LED_BUILDINを避難
    [LaunchController.kicad_pcb, LaunchController.kicad_sch]
2023-10-15 ステータスパネルの外形を追加
    [StatusPanel.kicad_pcb, StatusPanel.kicad_sch]
2023-10-15 LEDスイッチ類の取り付け穴を追加
    [StatusPanel.kicad_pcb, StatusPanel.kicad_sch]
2023-10-15 フォルダ構成を変更
    [StatusPanel.kicad_pcb, StatusPanel.kicad_sch]
2023-10-16 ステータスパネルの3Dモデルを生成
    [Button.step, LED_Bracket_Blue.step, LED_Bracket_Green.step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]
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2023-10-21 ランコンの回路図の修正点を書き込んだ紙をスキャンして入れといた
2023-10-22 パーツリスト更新
    [PartsList.xlsx]
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2023-10-23 USBのTX，RXを統合してACCESSに変更
    [Extension.kicad_sch, Indicator.kicad_sch, LaunchController.kicad_pcb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]
2023-10-23 充填確認スイッチ用のコネクタを別に用意
    [Extension.kicad_sch, LaunchController.kicad_pcb]
2023-10-23 CAUTIONをERRORに名称変更
    [Extension.kicad_sch, Indicator.kicad_sch, LaunchController.kicad_pcb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]
2023-10-23 RS485をモジュラージャックからプッシュインコネクタに変更
    [LaunchController.kicad_pcb, Peripheral.kicad_sch]
2023-10-23 ステータスパネルを再設計
    [7SEG.step, Button.step, LED_Bracket_Blue.step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]
2023-10-24 ステータスパネルの裏面に配線を追加
    [DF51A-6DP-2DSA.stp, StatusPanel.kicad_pcb, StatusPanel.kicad_sch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]
2023-10-24 抵抗値を決定
    [StatusPanel.kicad_pcb, StatusPanel.kicad_sch]
2023-10-24 ランコンのKiCadプロジェクトをコピーしてサテコンを作成
    [Extension.kicad_sch, Indicator.kicad_sch, Peripheral.kicad_sch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]
2023-10-24 音声完成を削除
    [Extension.kicad_sch, Indicator.kicad_sch, Peripheral.kicad_sch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]
2023-10-24 手動操作を削除
    [Extension.kicad_sch, Indicator.kicad_sch, SatelliteController.kicad_pcb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]
2023-10-24 残った手動制御を削除
    [Peripheral.kicad_sch, SatelliteController.kicad_pcb]
2023-10-24 7セグ用のコネクタを移動
    [SatelliteController.kicad_pcb]
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2023-11-07 パーツリストの在庫数を修正
    [PartsList.xlsx]
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2023-11-24 抵抗値を修正
    [Power.kicad_sch, SatelliteController.kicad_pcb]
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2023-12-01 サテコンのオープン検知を修正
    [Relay.kicad_sch, SatelliteController.kicad_pcb]
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2023-12-01 ストップでフラグを解除するように修正
2023-12-01 エマスト中にも穏便ストップできるように修正
2023-12-01 関数名を間違えていたので修正
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2024-05-04 FB_SHIFTの配線を修正
    [Indicator.kicad_sch, SatelliteController.kicad_pcb]
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2024-05-04 7セグで9が正しく表示されるように修正
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2024-05-04 シーケンス進行のフラグを修正
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2024-05-10 文法上のミスを修正
    [LaunchController.kicad_pcb]
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2024-05-23 シルクを修正
    [Peripheral.kicad_sch, SatelliteController.kicad_pcb]
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2024-11-20 オートパージ時にdumpがopenになる動作を修正
2024-11-22 timeoutの時間を修正
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2024-12-27 スペルミスを修正
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2025-01-15 フォルダ構成の見た目を修正
2025-01-16 ドキュメントの表示位置を修正
2025-01-16 リンクの間違いを修正
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2025-02-18 点火シークエンスの誤りを修正
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2025-03-27 リンクのミスを修正
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2025-06-26 重複していたので修正
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2026-01-23 .gitignore が反映されなかったので修正
    [7SEG.step, BranchAdapter.kicad_pcb, BranchAdapter.kicad_sch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]
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2026-02-18 通信エラー時はエラーランプがONになるように修正
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2026-02-18 INPUTライブラリを修正
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2026-05-04 USB＋，USB－の配線を修正
    [LaunchController2.0.kicad_pcb, LaunchController2.0.kicad_sch]
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2026-08-13 GUIを修正
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2026-08-13 アンドンの表示を修正
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2026-08-29 再起動を繰り返さないように修正
2026-08-29 電圧の表示を修正
2026-08-29 電圧表示を修正
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2026-08-29 Fix CRC8 calculation to exclude packet_id
    [raspi_gse_control.py]
2026-08-29 Fix floating pin issue by enabling INPUT_PULLUP for active-low inputs
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
